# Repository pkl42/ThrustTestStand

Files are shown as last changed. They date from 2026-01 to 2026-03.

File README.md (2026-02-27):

# Motor Thrust Test Stand (ESP32)

An ESP32-based brushless motor thrust test stand for measuring, logging, and analyzing propulsion data of brushless motors and propellers via a web-based interface.

The system controls a brushless ESC, reads multiple sensors in real time, performs automated thrust test sequences using configurable test protocols, and exports results as CSV files for further analysis.

This project was inspired by:  
<https://github.com/avenhaus/thrust_stand/tree/main>  
<https://github.com/iforce2d/thrustTester>  
<https://www.tytorobotics.com/pages/series-1580-1585>

---

## Features

- Brushless motor ESC control (manual and automated)
- Real-time measurement of:
  - Thrust
  - Torque
  - Current
  - Voltage
  - Electrical power
  - RPM
  - Temperature
- Aggregated values including power and thrust-to-power ratio
- **JSON-based test protocols**
  - Multiple protocol definitions supported
  - Up to **10 test protocols stored persistently** on the device
  - Protocols can be uploaded, selected, and executed via the Web UI
- Automated thrust tests based on customizable test protocols
- Live web-based user interface (ESP32 Access Point)
- CSV export of test data
- Sensor calibration via web interface
- Persistent configuration using NVS
- LittleFS-based filesystem

### Safety Features

- Hardware Emergency Stop (E-Stop)
- Propeller cage door safety switch
- **Configurable safety trip concept**
  - Monitors critical parameters such as current, voltage, temperature, RPM, and thrust
  - Automatic motor shutdown when limits are exceeded
  - Safety trips are active during both manual and automated operation
- Visual system state indication via RGB status LED

---

## System Overview

The Thrust Test Stand software is divided into three main components.

### ThrustStand

Hardware abstraction and data acquisition layer:

- Initializes and updates all sensors
- Controls the ESC and throttle
- Accumulates and averages sensor data
- Provides a machine-level state snapshot without UI logic

### ThrustTestController

Automated test execution layer:

- Step-based throttle sequencing
- Acceleration, hold, and deceleration timing
- Test progress tracking
- Execution of stored test protocols
- Test metadata handling (motor, ESC, propeller)
- CSV export to LittleFS

### WebServerController

Web-based control and visualization layer:

- ESP32 operates as a Wi-Fi Access Point
- REST-style API endpoints
- Live JSON status updates
- Sensor calibration endpoints
- Test protocol management (upload, select, delete)
- Test control (start/stop)
- CSV download
- Static HTML/JavaScript frontend served from LittleFS

---

## Documentation

Additional documentation has been split into dedicated files:

- **Hardware design, wiring, and sensors:**  
  [README_Hardware.md](README_Hardware.md)

- **Test protocol format and execution model:**  
  [README_TestProtocol.md](README_TestProtocol.md)

---

## Media

- Overall test stand  
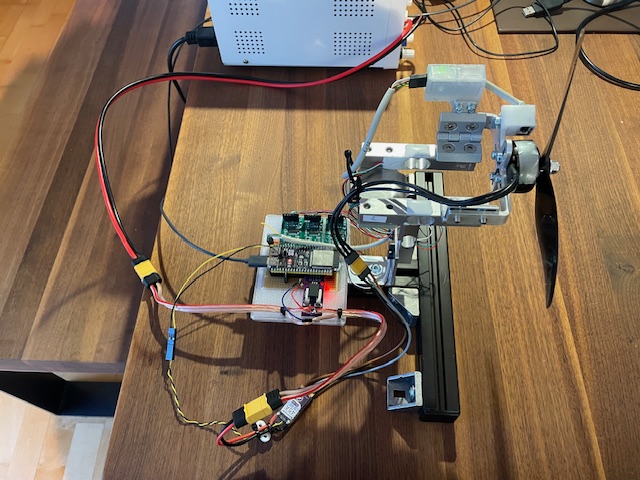
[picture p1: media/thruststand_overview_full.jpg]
Test Stand Overview
  

- ESP32 and sensor electronics overview  
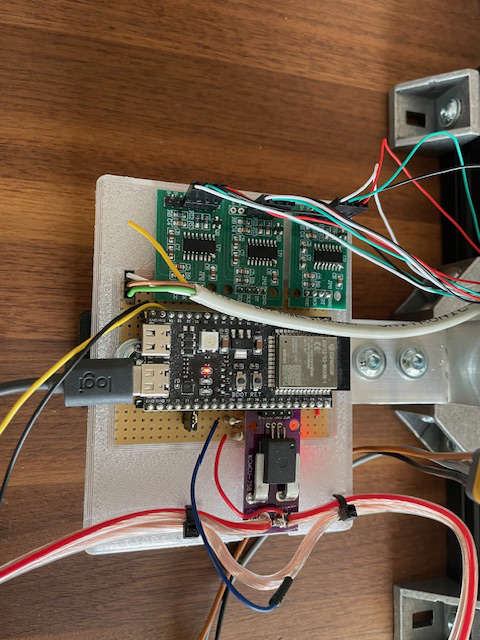
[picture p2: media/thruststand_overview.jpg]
ESP32 Electronic Overview
  

- Web UI Frontend with Live and Test-Section  
Additional Sections are System State, Safety, Configuration, Protocols  
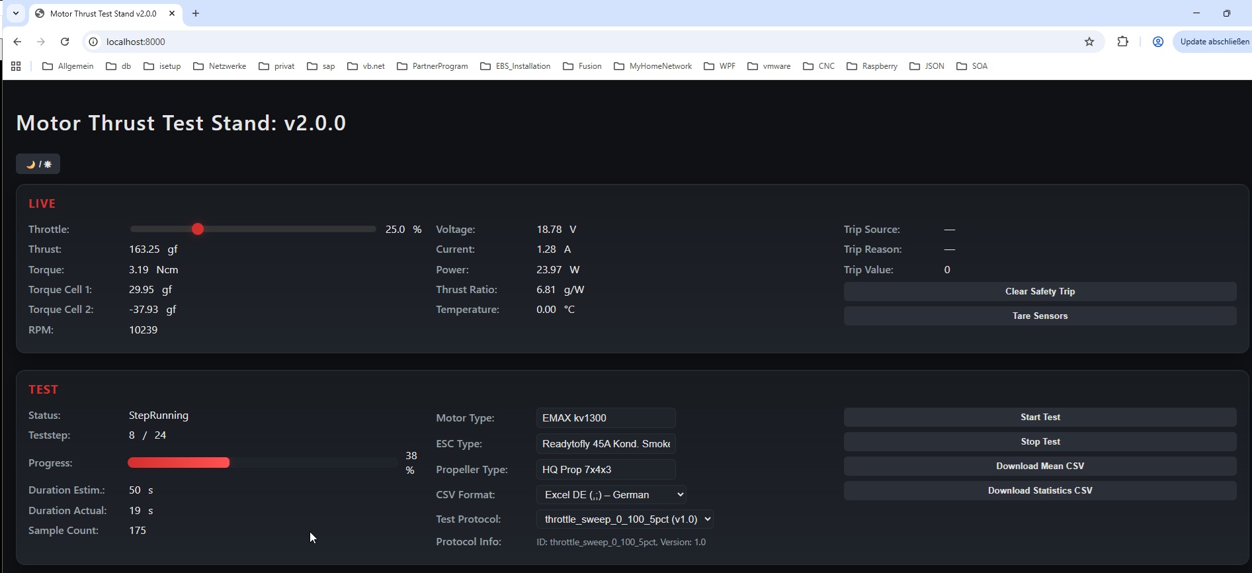
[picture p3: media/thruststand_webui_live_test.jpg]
WEB Front End


---

## Test Data

Each automated test step records:

- Throttle percentage
- Thrust (gf)
- Torque (Ncm)
- Voltage (V)
- Current (A)
- Electrical power (W)
- Efficiency (gf/W)
- RPM
- Temperature (°C)

Data is buffered in memory during the test and written to LittleFS as a CSV file upon completion.

---

## Build Environment

- PlatformIO
- ESP32 Arduino Framework
- Libraries:
  - ESPAsyncWebServer
  - AsyncTCP
  - HX711_ADC
  - Adafruit ADS1X15
  - Adafruit MAX31855
  - Adafruit MLX90614
  - INA226
  - LittleFS

---

## Recent Changes

See [CHANGELOG.md](CHANGELOG.md) for a full list of improvements and fixes.  

---

## Safety Notice

This system controls high-power rotating machinery.

- Always ensure the Emergency Stop is accessible
- Secure the motor and propeller firmly
- Never stand in the propeller plane
- Perform initial tests at low throttle settings

---

## License

Licensed under the Apache License, Version 2.0.

<http://www.apache.org/licenses/LICENSE-2.0>

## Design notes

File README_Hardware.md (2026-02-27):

## Hardware

### Media

Some Images of how the hardware is build up.

- ESP32 Adapter and sensor electronics Top View  
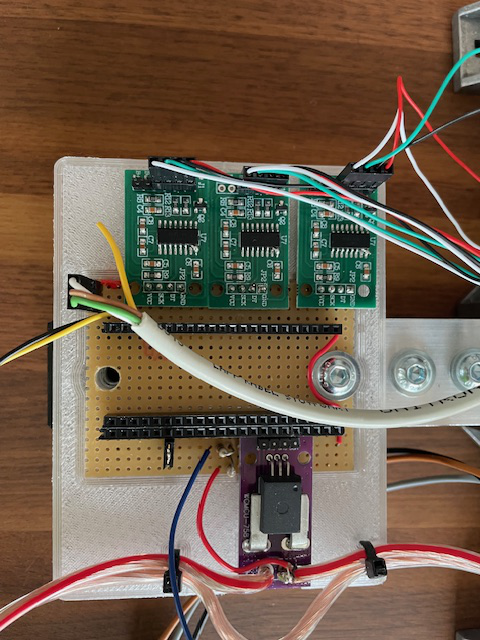
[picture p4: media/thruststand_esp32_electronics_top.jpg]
ESP32 and Sensor Electronics
  
  
- ESP32 Adapter and sensor electronics Bottom View  
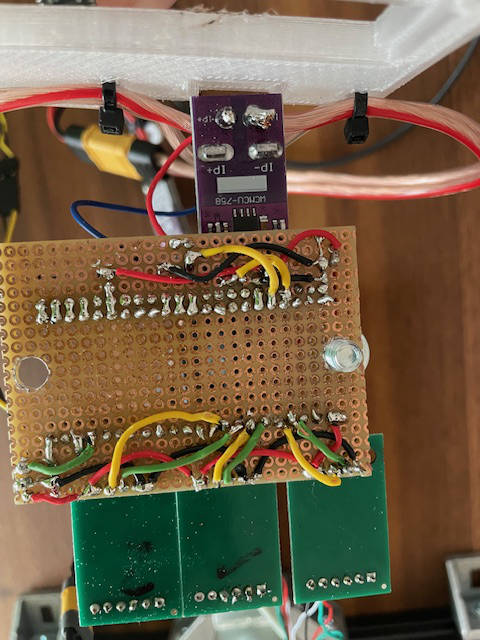
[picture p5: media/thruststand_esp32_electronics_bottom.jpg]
ESP32 and Sensor Electronics
  
  
- Infrared RPM sensor detail  
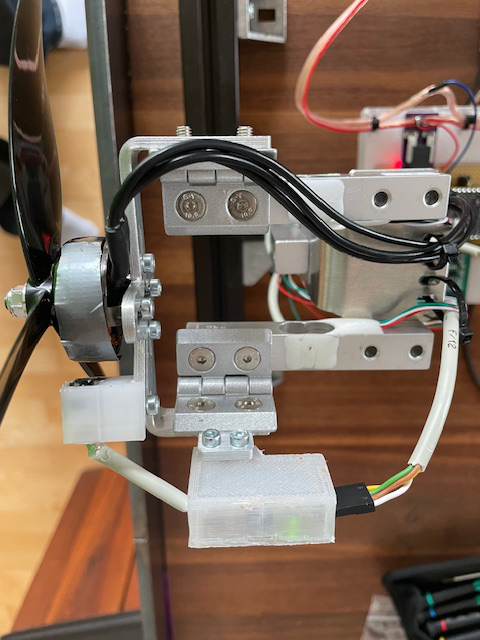
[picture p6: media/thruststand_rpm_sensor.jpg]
Infrared RPM Sensor
  

### Microcontroller

- ESP32-S3 WROOM-1 DevKit

### Sensors

- Thrust:
  - Load cell (5 kg) with HX711 ADC
- Torque:
  - Dual load cells (2 x 2 kg) with HX711 ADC
  - Lever-arm based torque calculation
- Current:
  - ACS758 hall-effect current sensor 50 A
- Voltage:
  - Resistor divider (10 kOhm / 1 kOhm, max approx. 33 V) - see notes below for variants
- RPM:
  - Infrared reflective optical sensor (HW-870 Infrared sensor)
- Temperature:
  - Thermocouple sensor (MAX31855) - prepared but not yet used  
  - Infrared temperature sensor (MAX90614 - HW-691)

### Actuators and Safety

- Brushless ESC (PWM control)
- Configurable pulse range:
  - Default: 1000–2000 µs
  - Allowed: 800–2200 µs
- Hardware Emergency Stop (E-Stop)
- Propeller cage door safety switch
- RGB status LED

---

## Wiring / Pin Assignment

### ESP32-S3 WROOM-1 Pin Mapping

**Note:** All sensors are connected on 3.3V to ESP32 board.

| GPIO | Signal / Name | Direction | Connected Hardware | Notes |
|-----:|---|---|---|---|
| 0* | BOOT | Input | Boot button | Strapping pin |
| 1 | CURRENT_SENSOR_PIN | Input (ADC) | ACS758 current sensor OU2| Current measurement |
| 2 | VOLTAGE_SENSOR_PIN | Input (ADC) | Voltage divider (10k / 1k) | Max ~33 V |
| 4 | HX711_DOUT_1_PIN | Input | HX711 #1 (Thrust, 5 kg) | Data DT|
| 5 | HX711_SCK_1_PIN | Output | HX711 #1 (Thrust, 5 kg) | Clock SCK|
| 6 | HX711_DOUT_2_PIN | Input | HX711 #2 (Torque cell 1, 2 kg) | Data DT|
| 7 | HX711_SCK_2_PIN | Output | HX711 #2 (Torque cell 1, 2 kg) | Clock SCK|
| 13 | RPM_SENSOR_PIN | Input | IR reflective RPM sensor | Digital pulse input DOUT |
| 14 | MOTOR_ESC_PIN | Output (PWM) | Brushless ESC | Throttle control |
| 15 | HX711_DOUT_3_PIN | Input | HX711 #3 (Torque cell 2, 2 kg) | Data DT|
| 16 | HX711_SCK_3_PIN | Output | HX711 #3 (Torque cell 2, 2 kg) | Clock SCK|
| 17 | MAX31855_CS_PIN | Output | MAX31855 thermocouple | SPI chip select |
| 38 / 48 | RGB_BUILTIN_LED | Output | Onboard RGB LED | Status indication |
| 41 | I2C_SCL | I/O | I2C bus | Optional |
| 42 | CAGE_SWITCH_PIN | Input | Cage Door Open/Close Switch | Active safety input |
| 43 | UART_TX0 | Output | USB / Serial | Debug |
| 44 | UART_RX0 | Input | USB / Serial | Debug |
| 47 | ESTOP_PIN | Input | Emergency Stop | Active safety input |

- Strapping pins: GPIO 0, 3, 45, 46. Avoid changing their state during boot.

### Wiring Load Cells to HX711 board

|Wire Color | HX711 board |
|---|---|
| red | E+ |
| black | E- |
| green | A- |
| white | A+ |
| n.c. | B- |
| n.c. | B+ |

### Wiring Infrared Sensor

| Signal/Name |Wire Color  | TCRT5000 IR Infrared board |
|---|---|---|
| 3.3V |white  | Vcc |
| Ground |brown  | GND |
| D0 |green  | D0ut |
| A0 |yellow (n.c.)  | A0 |

### Wiring Current Sensor ASC758

| Signal/Name | Current Sensor ASC758 board |
|---|---|
| 3.3V | Vcc |
| Ground  | GND |
| n.c.  | OU1 |
| CURRENT_SENSOR_PIN,corresponding Voltage | OU2 |

### Wiring ESC

| Signal/Name |Wire Color  |ESC |
|---|---|---|
| GND | black |GND |
| MOTOR_ESC_PIN (PWM) | orange or whie | Signal |

---

Very helpful additions can be found at:
<https://github.com/iforce2d/thrustTester/tree/master>

### Motor speed controller

The ESC should use standard PWM. The default calibration range is 1000 µs for zero throttle and 2000 µs for full throttle.  
The software allows modifying this range from 800 µs to 2200 µs.

To find the correct settings for your ESC, unmount the propeller and move the throttle in the WEB UI to 100%.  
You should reach the maximum motor speed (kv-value × voltage) at 100%.  
If not, increase or decrease the *Max Pulse (µs)* value in the Calibration section of the WEB UI.

### Load cell amplifier

The HX711 can operate at either 10 Hz or 80 Hz update rate. Obviously, the faster rate is preferred, but most HX711 module boards are configured for 10 Hz by default.

To change the update rate to 80 Hz, disconnect the RATE pin (pin 15) from the PCB pad it is soldered to and connect it to VCC.  
The easiest way is to solder it to pin 16, which is located directly next to it.

**Important:** Make sure pin 15 is completely disconnected from the PCB pad. Otherwise, you risk a short circuit when connecting it to VCC.

Please see further details at:
<https://github.com/iforce2d/thrustTester/tree/master>

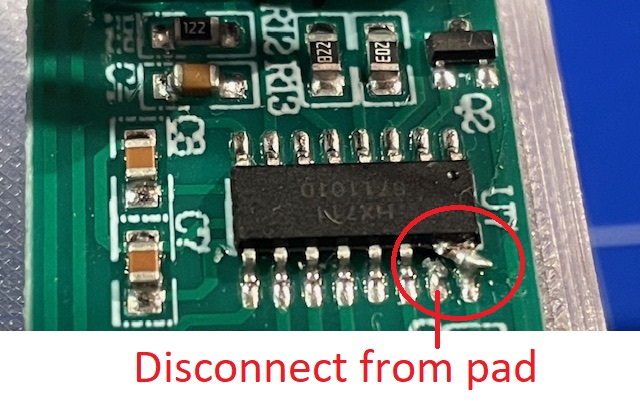
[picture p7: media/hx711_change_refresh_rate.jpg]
HX711 Refresh Rate


The load cells have an arrow indicating the direction of the applied force.  
This arrow should point in the direction where the force is acting, although the load cell will work in both directions.

#### Calibration procedure

1. In the Calibration section, set the *Thrust Cal-Factor* to **1**.
2. In the Live section, press the **“Tare Sensors”** button.
3. Place a defined weight at the center point of the propeller mount.
4. The calibration factor is calculated as:

   **Cal-Factor = Thrust value (Live view) / defined weight**

For calibration, a deflection holder was built to apply the defined weight:

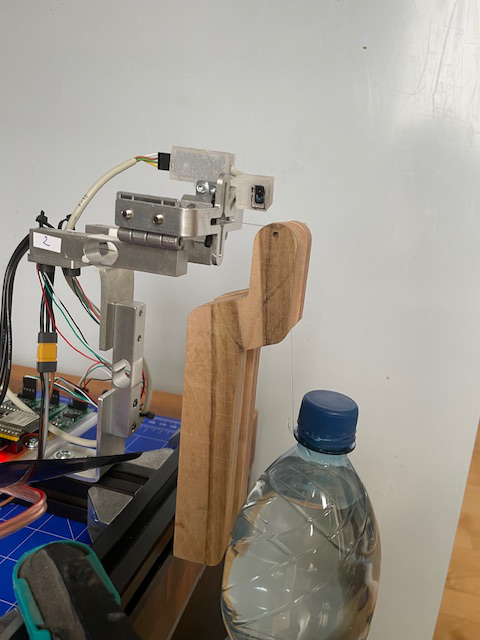
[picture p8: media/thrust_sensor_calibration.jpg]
deflection holder


The water bottle is suspended using a nylon cord and fixed at the center point with a screw or pin, as shown in the picture of the RPM sensor.

Another method is to rotate the thrust stand so the defined weight can be hung directly from the center point.

During calibration, the measured thrust value may drift (slowly decreasing) the longer the weight is applied.  
This behavior is typical for low-cost load cells. To reduce this effect, load cells with an accuracy class such as **C3** or **C4** should be used.

#### Torque sensor calibration

For calibrating the torque sensor, unmount the motor plate (or loosen the hinge screws) so that both load cells do not influence each other.  
This is also the reason why hinges are used for each torque load cell.

To simplify calibration, the torque sensor reports the **absolute torque value**, without information about the direction of rotation.

### Units & Calibration Philosophy

Although thrust is physically a force and its SI unit is **Newton (N)**, this project intentionally uses **grams (g)** as its primary internal unit.  
More precisely, all load-cell-based measurements are expressed in **gram-force (gf)**.

This choice is based on the calibration chain:

- Load cells measure force
- Calibration is performed using a known weight
- The reference weight is determined using a scale that displays grams
- The calibration therefore maps HX711 raw values directly to gram-force

As a result, the internal unit `g` represents **gram-force (gf)**, i.e. the force exerted by a mass of 1 g under Earth gravity.

This approach:

- Matches motor and propeller datasheets, which commonly specify thrust in grams
- Keeps calibration simple and intuitive
- Avoids embedding the gravitational constant into the calibration factor
- Ensures consistency across all load-cell-based measurements

**Torque measurement:**  
Motor torque is measured using two load cells and a known lever arm distance. Internally, torque is represented in **g·m (gram-force meters)**, which is fully consistent with the thrust unit.

For applications requiring SI units, conversion is straightforward:

- 1 g (gf) ≈ 0.00980665 N  
- 1 g·m ≈ 0.00980665 Nm

### Voltage Sensor

The voltage sensor uses a resistor divider of 10 kΩ / 1 kΩ.  
This limits the maximum measurable battery voltage to **36.3 V**, as the ESP32 ADC input must not exceed 3.3 V.  
Keep in mind that on a hard motor stop the voltage will spike. For 6S Batteries (25.2 nominal) this should work.  

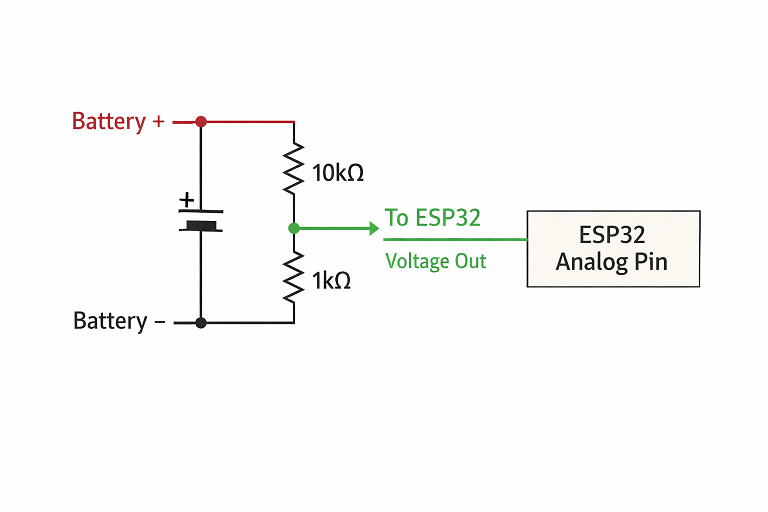
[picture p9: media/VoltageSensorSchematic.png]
Voltage Divider


For more security replace the 1 kΩ by a 820 Ω.  

Since the battery negative terminal must be connected to the ESP32 GND, a pin was directly inserted into the cable.

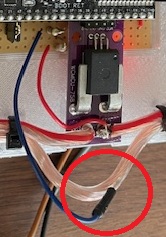
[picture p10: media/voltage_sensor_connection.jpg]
Voltage Minus Connection


For calibration, a laboratory power supply was used and set to a known voltage (e.g. 22 V).  
Adjust the *Voltage Calibration* value in the Calibration section until the displayed live voltage matches the PSU value.

Because the ADC is highly linear, the calibration factor is limited to a range between **0.9 and 1.1**.

### Current Sensor ACS758

The 50 A version of the ACS758 sensor was used, together with a 2.5 mm² cable for the battery current path.  
Even ESCs rated at 45 A (e.g. Flycolor 45A) typically use AWG16 (1.31 mm²), so this setup is sufficiently robust.

In tests with currents up to 33 A, the cable did not heat up.  
XT60 connectors are used between the battery/PSU, current sensor, and ESC.

Calibration options:

1. Manually set the **Current Sensitivity** value (volts per amp), or  
2. Run the motor using a PSU at a known current (e.g. 8 A shown on the PSU) and enter this value into **“Actual Current (A)”**, then press **Set**.

### RPM Sensor TCRT5000 IR Infrared

The IR sensor core was desoldered and repositioned close to the motor rotor.  
Although the sensor sensitivity can be adjusted using a potentiometer, it is difficult to obtain a clean signal due to rotor reflections.

A strip of duct tape was used as a reflective marker, while the rest of the rotor was colored black using a non-permanent whiteboard marker.  
The tape covers approximately half the rotor circumference.

This setup works as long as ambient sunlight is not too strong. A laser-based sensor may be a better alternative.

Tests using propeller reflections were also performed, but at higher RPM the reflection time was too short for reliable detection.

---

## 3D Print Parts Notes

- ESP32 mounting plate: `cad/ESP32SensorAdapter.step`
- Infrared sensor housing: `cad/InfraredSensorHousing.step`
- Electronics housing:
  - `cad/ElectronicHousing.step`
  - `cad/ElectronicHousingCover.step`

M3 heat-set inserts are used for mounting.

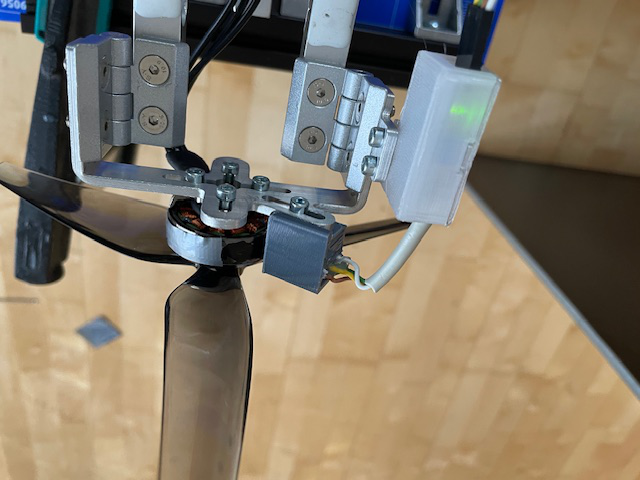
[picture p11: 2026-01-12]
media/rpm_sensor_mount_2.jpg

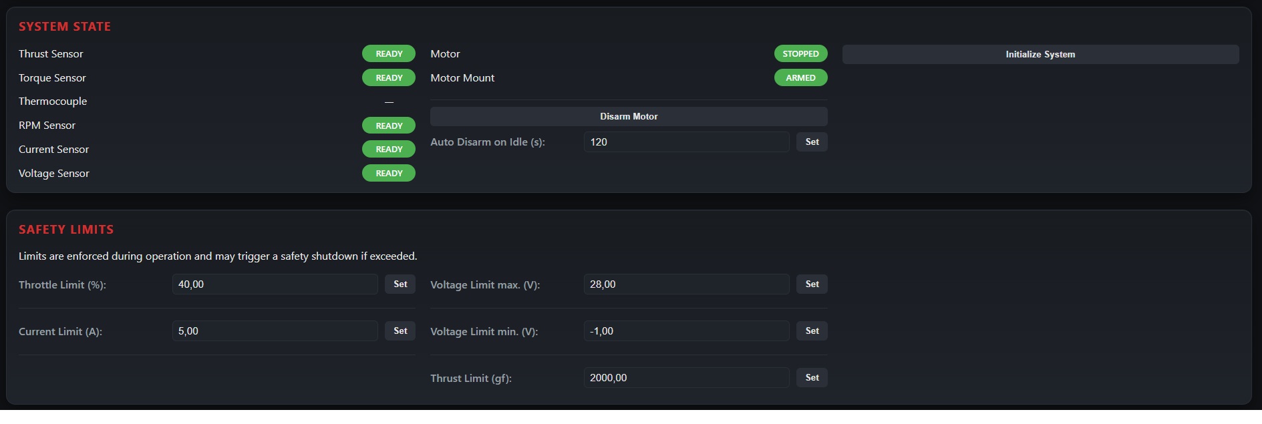
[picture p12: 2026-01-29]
media/thruststand_webui_system_safety.jpg

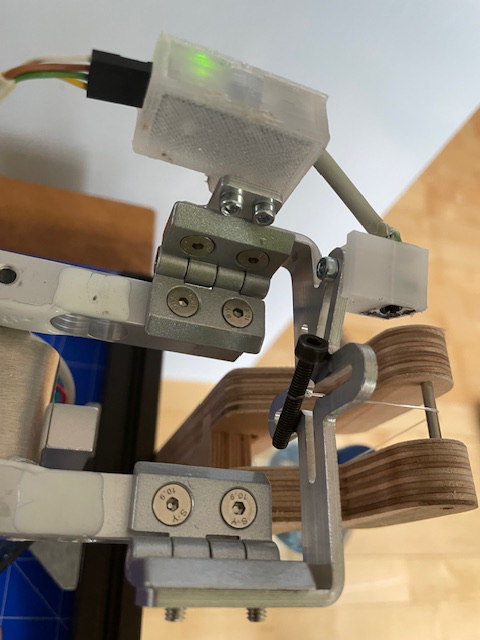
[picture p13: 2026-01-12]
media/rpm_sensor_mount_1.jpg

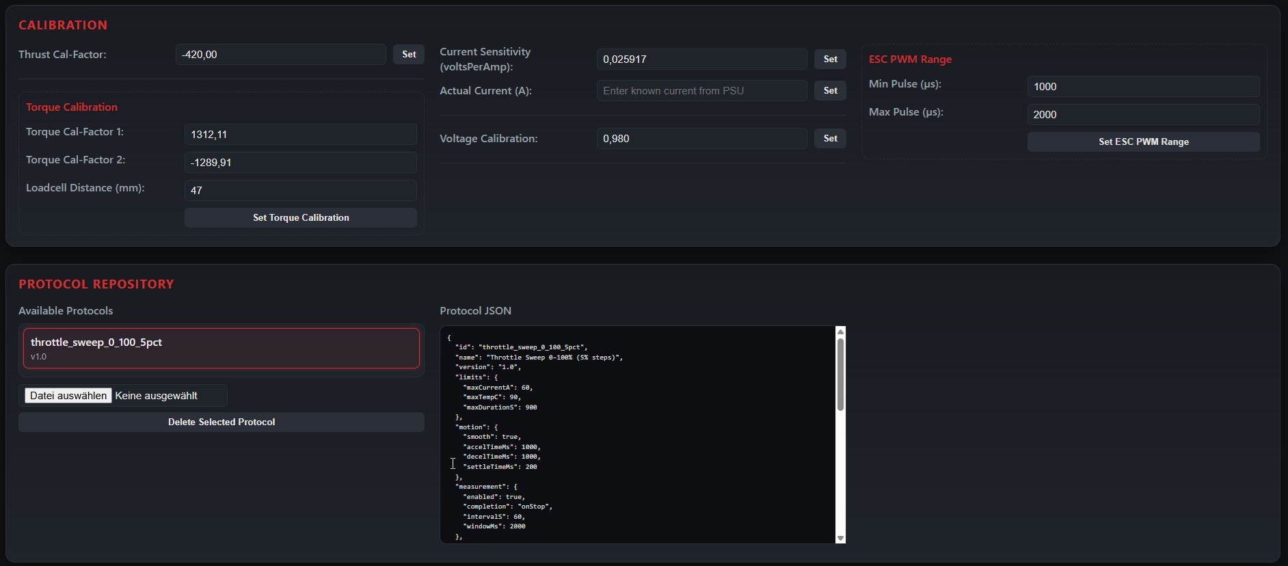
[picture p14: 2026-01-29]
media/thruststand_webui_calib_protocols.jpg

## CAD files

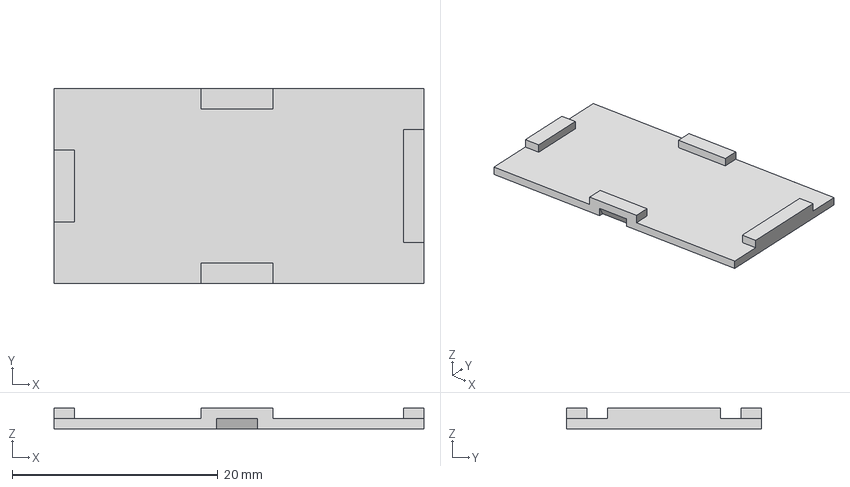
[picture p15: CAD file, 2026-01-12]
cad/ElectronicHousingCover.step
36.0 x 19.0 x 2.00 mm

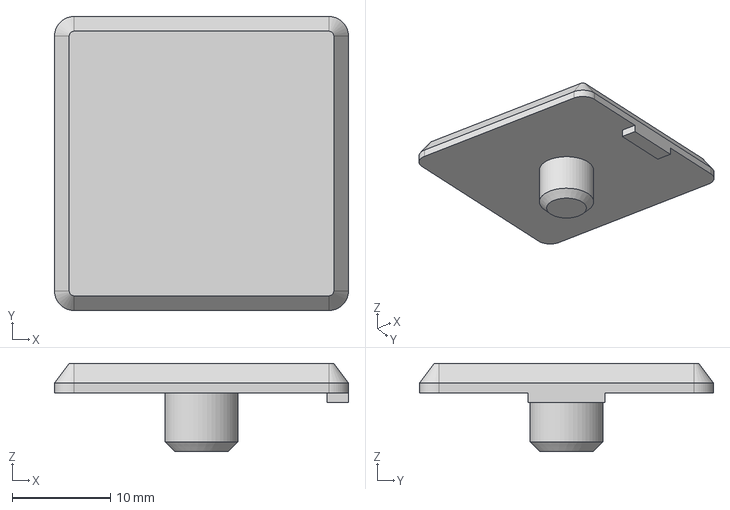
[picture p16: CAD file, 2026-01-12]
cad/Abdeckkappe_20x20 v4.step
30.0 x 30.0 x 9.00 mm

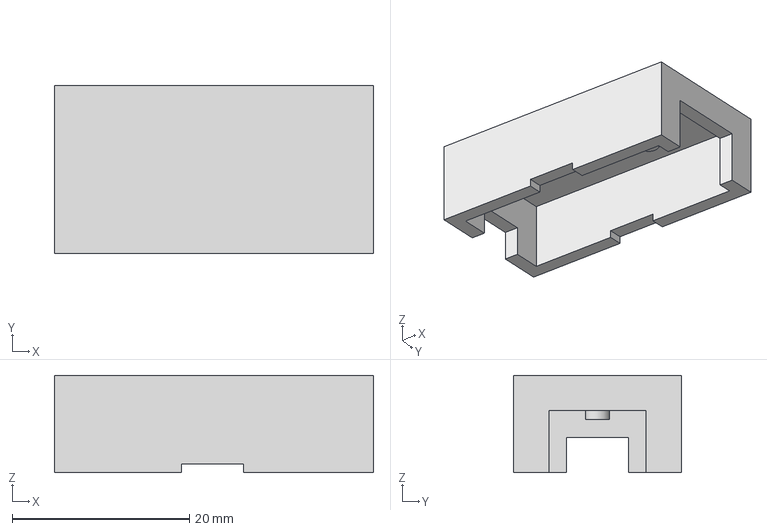
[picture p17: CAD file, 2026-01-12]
cad/ElectronicHousing.step
36.0 x 19.0 x 11.0 mm

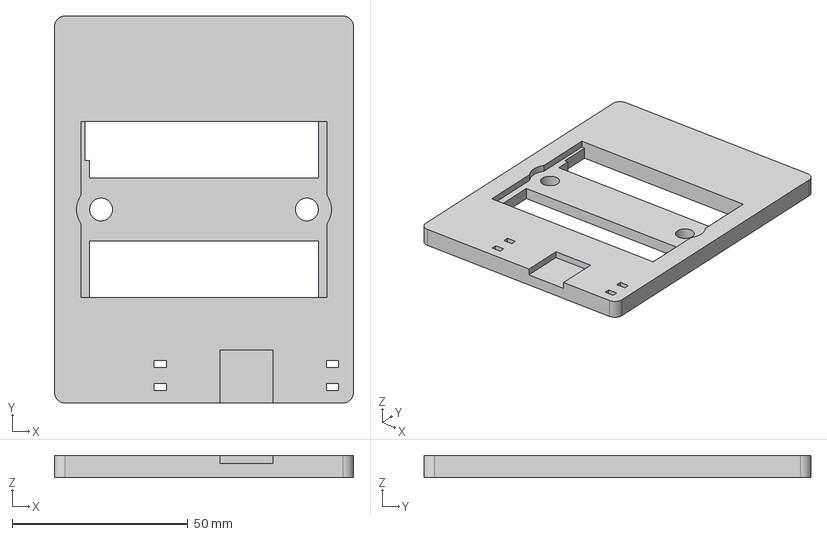
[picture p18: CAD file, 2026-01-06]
cad/ESP32SensorAdapter.step
85.0 x 110.0 x 6.30 mm

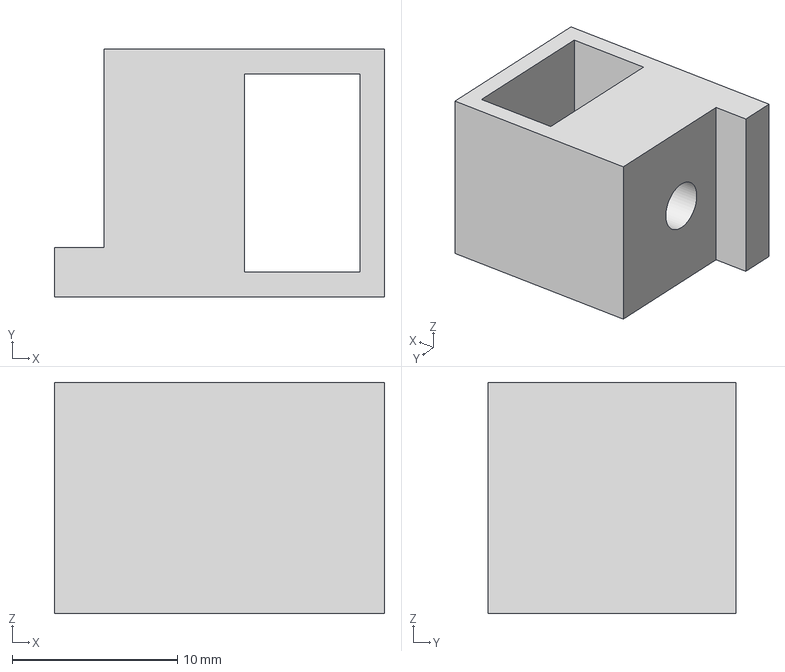
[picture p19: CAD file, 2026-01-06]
cad/InfraredSensorHousing.step
20.0 x 15.0 x 14.0 mm

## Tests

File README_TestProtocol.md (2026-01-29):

# Motor Thrust Test Stand – Test Protocols

This document explains how to define and use **test protocols** for the Motor Thrust Test Stand. Protocols are JSON documents that describe the sequence of steps, motion parameters, measurement configuration, and safety limits.

The goal of the protocol format is to be **safe by default**, **easy to read**, and **flexible where allowed**.

---

## 1. Protocol JSON Structure

A test protocol JSON has the following main sections:

```text
{
  "id": "<unique protocol ID>",
  "name": "<human-readable name>",
  "version": "<protocol version>",
  "estDurationS": 0,
  "unitsTotal": 0,
  "limits": { ... },
  "motion": { ... },
  "measurement": { ... },
  "steps": [ ... ]
}
```

---

## 2. Required vs Optional Fields

### 2.1 Required Fields

| Field | Type | Description |
|---|---|---|
| `id` | string | Unique identifier for the protocol |
| `name` | string | Human-readable name |
| `version` | string | Version of the protocol (e.g. `"1.0"`) |
| `steps` | array | Array of protocol steps |

---

### 2.2 Optional Fields and Default Resolution

All other sections (`limits`, `motion`, `measurement`) are **optional**.

They follow a strict **three-level resolution order**:

1. **Firmware defaults** (defined in the thrust stand firmware)
2. **Protocol header values** (top-level JSON fields)
3. **Step-level overrides** (inside individual steps)

If a field is omitted, the value from the previous level is used.

> **Important:**  
>
> - Firmware defaults always exist and are never undefined  
> - Step-level values only override the fields they explicitly define  

---

## 3. Safety Limits and Non‑Weakening Rules

Safety limits are treated differently from other optional fields.

### 3.1 Sources of Safety Limits

Safety limits can originate from three places:

1. **Firmware hard limits**  
   Absolute safety bounds compiled into the thrust stand firmware, which represents the hardware/sensor limits.

2. **Web UI safety configuration**  
   User-configured safety limits set before starting a test.

3. **Protocol limits**  
   Limits defined in the protocol JSON.

---

### 3.2 Non‑Weakening Principle (Critical)

Safety limits **can only become more restrictive**, never weaker.

This applies at every level:

- Protocol limits **cannot exceed firmware hard limits**
- Protocol limits **cannot exceed Web UI safety settings**
- Step-level limits **cannot exceed protocol limits**

If a protocol requests a weaker limit, the **more restrictive value wins silently**.

---

### 3.3 Limits Section

Defines maximum safe operating parameters:

```json
"limits": {
  "maxCurrentA": 30.0,
  "maxTempC": 80.0,
  "maxDurationS": 900,
  "maxVoltageV": 24.0,
  "minVoltageV": 18.0,
  "maxThrustGF": 5000.0
}
```

| Field | Description | Firmware Setting |
|---|---|---|
| `maxCurrentA` | Maximum allowed motor current (A) | 48 A, see Config.h CURRENT_SENSOR_MAX |
| `maxTempC` | Maximum allowed temperature (°C) | 120 C, see Config.h TEMPERATURE_SENSOR_MAX |
| `maxDurationS` | Maximum allowed test duration (seconds) | 2592000, representing 1 month |
| `maxVoltageV` | Maximum allowed supply voltage | 35 V, see Config.h VOLTAGE_SENSOR_MAX |
| `minVoltageV` | Minimum allowed supply voltage |-1 V, softcoded |
| `maxThrustGF` | Maximum allowed thrust (gram-force) | 5000 g, see Config.h THRUST_SENSOR_MAX |

> If any of these are omitted, the resolved value is taken from firmware or Web UI settings.

---

## 4. Motion Defaults and Overrides

### 4.1 Protocol-Level Motion Defaults

Defines default motion parameters for all steps:

```json
"motion": {
  "smooth": true,
  "accelTimeMs": 1000,
  "decelTimeMs": 1000,
  "settleTimeMs": 200
}
```

| Field | Description |
|---|---|
| `smooth` | Enable throttle smoothing |
| `accelTimeMs` | Acceleration time in milliseconds |
| `decelTimeMs` | Deceleration time in milliseconds |
| `settleTimeMs` | Optional delay after motion completes |

---

### 4.2 Step-Level Motion Overrides

Each step may override motion settings:

```json
"motion": {
  "smooth": false,
  "accelTimeMs": 500
}
```

- Only specified fields override protocol defaults  
- Missing fields inherit protocol-level values  

---

## 5. Measurement Defaults and Overrides

### 5.1 Protocol-Level Measurement Defaults

```json
"measurement": {
  "enabled": true,
  "completion": "onStop",
  "intervalS": 60,
  "windowMs": 2000
}
```

| Field | Description |
|---|---|
| `enabled` | Enable data recording |
| `completion` | `onStop`, `fixedDuration`, or `periodic` |
| `intervalS` | Period between samples (seconds) |
| `windowMs` | Measurement window duration (ms) |

---

### 5.2 Step-Level Measurement Overrides

```json
"measure": {
  "enabled": true,
  "completion": "fixedDuration",
  "windowMs": 1000
}
```

- Only overridden fields are replaced  
- Missing fields inherit protocol-level values  

---

## 6. Steps Section

Each protocol consists of an ordered array of steps:

```json
"steps": [
  { "type": "set", "throttle": 0, "dwellS": 2 },
  { "type": "ramp", "from": 0, "to": 100, "rate": 5 }
]
```

### 6.1 Supported Step Types

| Type | Required Fields | Description |
|---|---|---|
| `set` | `throttle`, `dwellS` | Set throttle and hold |
| `hold` | `throttle`, `dwellS` | Maintain throttle |
| `ramp` | `from`, `to`, `rate` | Continuous ramp |
| `stepSweep` | `from`, `to`, `step`, `dwellS` | Discrete sweep |

---

## 7. Example Protocol

```json
{
  "id": "throttle_sweep_0_100_5pct",
  "name": "Throttle Sweep 0–100% (5% steps)",
  "version": "1.0",

  "limits": {
    "maxCurrentA": 60,
    "maxTempC": 90
  },

  "motion": {
    "smooth": true,
    "accelTimeMs": 1000,
    "decelTimeMs": 1000
  },

  "measurement": {
    "enabled": true,
    "completion": "onStop",
    "windowMs": 2000
  },

  "steps": [
    {
      "type": "set",
      "throttle": 0,
      "dwellS": 2,
      "measure": { "enabled": false }
    },
    {
      "type": "stepSweep",
      "from": 0,
      "to": 100,
      "step": 5,
      "dwellS": 2,
      "measure": {
        "completion": "fixedDuration",
        "windowMs": 1000
      }
    }
  ]
}
```

---

## 8. Key Takeaways

- Firmware defaults always exist  
- Protocol headers define defaults for all steps  
- Steps override only what they explicitly define  
- Safety limits **never weaken**, only tighten  
- Unsafe values are automatically clamped  

This design keeps protocols expressive while guaranteeing safe operation at all times.

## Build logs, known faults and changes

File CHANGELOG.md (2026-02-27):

# Changelog

All notable changes to the Motor Thrust Test Stand project will be documented in this file.

This project does not currently use formal releases.
Changes are documented chronologically.

---

## [Unreleased]

### Added

-

### Changed

-

### Fixed

-

### Removed

-

---

## [v2.2.0] 2026-02-27

### Added

- DShot ESC driver support (configurable RMT channel), but the whole DShot is not working as of now.
- MLX90614 I2C temperature sensor integration
- Sensor abstraction layer to integrate various sensors with the scope (TemperatureSensor)

### Changed

- Refactored `ThrustStand::switchDriver()` to support dynamic driver configuration
- Updated pin configuration structure
- Resolve pin conflict CAGE_SWITCH_PIN, RPM_SENSOR_PIN when using MLX90614 (I2C) or MAX31855 (SPI)

### Fixed

- index.hmtl, main.js were not in sync with github
- After E-Stop, system can be restarted
- Pullup/Pulldown pin logic on E-Stop corrected (inverted)

---

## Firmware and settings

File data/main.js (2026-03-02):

	function setValue(id, value, digits) {
		const el = document.getElementById(id);
		if (!el || value === undefined) return;
		el.value = (typeof digits === "number") ? value.toFixed(digits) : value;
	}
	
	function refreshFromButton(btn) {
		const fieldset = btn.closest('fieldset');
		const apiPath = fieldset?.dataset.api || btn.dataset.api;

		fetch(apiPath)
			.then(r => {
				if (!r.ok) throw new Error("Refresh failed");
				return r.json();
			})
			.then(data => {
				const scope = fieldset || document;

				scope.querySelectorAll('input').forEach(input => {
					if (data.hasOwnProperty(input.id)) {
						input.value = data[input.id];
					}
				});

				alert("Refreshed from device");
			})
			.catch(err => {
				alert("Error during refresh!");
				console.error(err);
			});
	}
	
	function postInputs(apiPath, inputs) {
		const payload = {};

		for (const input of inputs) {
			const path = input.id.split('.');
			let obj = payload;

			for (let i = 0; i < path.length - 1; i++) {
				if (!obj[path[i]]) obj[path[i]] = {};
				obj = obj[path[i]];
			}

			const value =
				input.type === 'number'
					? Number(input.value)
					: input.value;

			obj[path[path.length - 1]] = value;
		}

		// 🔑 Return the Promise
		return fetch(apiPath, {
			method: 'POST',
			headers: { 'Content-Type': 'application/json' },
			body: JSON.stringify(payload)
		})
		.then(r => {
			if (!r.ok) throw new Error("POST failed: " + r.status);
			// try to parse JSON, fallback to text
			return r.text().then(txt => {
				try { return JSON.parse(txt); } catch { return txt; }
			});
		})
		.catch(err => {
			console.error(err);
			alert("Failed to save settings");
			throw err; // propagate to handleAction .catch
		});
	}

	
	// Holds dirty flags for all sections
	const dirtyFlags = {};


	function updateDirtyUI(section) {
		const buttons = document.querySelectorAll(`button[data-section="${section}"]`);
		const isDirty = dirtyFlags[section];

		buttons.forEach(btn => {
			if (isDirty) {
				btn.classList.add('dirty'); // visual highlight only
			} else {
				btn.classList.remove('dirty');
			}
		});
	}
		
	function handleAction(btn) {
		const action = btn.dataset.action;
		const apiPath = btn.dataset.api;
		const rawParams = btn.dataset.params;

		let inputs = [];

		if (rawParams) {
			if (rawParams.endsWith('.*')) {
				// wildcard support, e.g. "limits.*"
				const prefix = rawParams.slice(0, -1); // "limits."
				inputs = Array.from(
					document.querySelectorAll(`input[id^="${prefix}"], select[id^="${prefix}"]`)
				);

			} else {
				// explicit list: a,b,c
				const ids = rawParams.split(',').map(s => s.trim());
				inputs = ids
					.map(id => document.getElementById(id))
					.filter(Boolean);
			}
		}

		if (action.includes('post') && inputs.length) {
			const section = inputs[0].dataset.section; // assume all inputs in same section
			
			console.log("POST inputs:", inputs.map(i => i.id));

			postInputs(apiPath, inputs)
				.then(() => {
					// only reset dirty flag if POST succeeded
					if (section) {
						dirtyFlags[section] = false;
						updateDirtyUI(section);
						// updateExecutionStatusUI(); // recompute isExecutable() if needed
					}
				})
				.catch(err => {
					console.error("Error posting data", err);
					alert("Failed to save settings. Changes not applied.");
				});
		}

		if (action.includes('refresh')) {
			if (btn.dataset.loader) {
				window[btn.dataset.loader]();
			} else {
				refreshFromButton(btn);
			}
		}
	}



	
	function toggleTheme() {
		const root = document.documentElement;
		const current = root.getAttribute("data-theme") || "dark";
		const next = current === "dark" ? "light" : "dark";
		root.setAttribute("data-theme", next);
		localStorage.setItem("theme", next);
	}

	(function initTheme() {
		const saved = localStorage.getItem("theme") || "dark";
		document.documentElement.setAttribute("data-theme", saved);
	})();
	
	

	function isExecutable() {
		const tripped = document.getElementById('safetyBanner').style.display === 'block';
		const dirty = dirtyFlags['safety']; // or iterate all relevant sections
		return !tripped && !dirty;
	}

	
	
	function postParam(apiPath, paramsObj, successMessage) {
		const params = new URLSearchParams();

		// Add each key-value pair from the object
		for (const [key, value] of Object.entries(paramsObj)) {
			params.append(key, value);
		}

		fetch(apiPath, {
			method: 'POST',
			headers: {
				'Content-Type': 'application/x-www-form-urlencoded'
			},
			body: params.toString()
		})
		.then(r => {
			if (!r.ok) throw new Error("Save failed");
			alert(successMessage);
		})
		.catch(err => {
			alert("Error during save!");
			console.error(err);
		});
	}
	
	
    /* -----------------------------
       CALIBRATION
    ------------------------------*/

	function loadCalibration() {
		fetch('/api/calibration')
			.then(r => {
				if (!r.ok) throw new Error("Calibration Values fetch failed");
				return r.json();
			})
			.then(cfg => {

				/* ---------- Version ---------- */
				if (typeof cfg.version === "string") {
					document.title = "Motor Thrust Test Stand " + cfg.version;

					const h1 = document.getElementById('page-title');
					if (h1) {
						h1.textContent = "Motor Thrust Test Stand: " + cfg.version;
					}
				}

				/* ---------- Thrust ---------- */
				setValue('thrust.cal', cfg.thrust?.cal, 2);

				/* ---------- Torque ---------- */
				setValue('torque.cal1',     cfg.torque?.cal1, 2);
				setValue('torque.cal2',     cfg.torque?.cal2, 2);
				setValue('torque.distance_mm', cfg.torque?.distance_mm);

				/* ---------- Current ---------- */
				setValue('current.sensitivity', cfg.current?.sensitivity, 6);

				/* ---------- Voltage ---------- */
				setValue('voltage.calibration', cfg.voltage?.calibration, 3);

				/* ---------- Motor PWM ---------- */
				setValue('motor.pwm_min_us', cfg.motor?.pwm_min_us);
				setValue('motor.pwm_max_us', cfg.motor?.pwm_max_us);
				
				/* ---------- Motor Auto Disarm ---------- */
				setValue('motor.disarm_timeout_s', cfg.motor?.disarm_timeout_s);
				
				/* ---------- ESC Driver Type ---------- */
				setValue('motor.esc_driver_type', cfg.motor?.esc_driver_type);
				const label = escDriverToLabel(cfg.motor?.esc_driver_type);

				setValue('test.esc_driver', label);
			})
			.catch(err => {
				console.error("loadCalibration failed:", err);
				alert("Failed to load calibration values");
			});
	}

	

    /* -----------------------------
       SAFETY LIMIT
    ------------------------------*/
	
	function enforceSafetyTrip() {
		const safetyBanner = document.getElementById('safetyBanner');
		const tripped = safetyBanner.style.display === 'block';

		const slider = document.getElementById('throttle');
		const startTestBtn = document.getElementById('test.start');

		if (tripped) {
			// Reset UI
			slider.value = 0;
			document.getElementById('throttleVal').innerText = "0";

			// Prevent slider interaction
			slider.disabled = true;
			startTestBtn.disabled=true;

		} else {
			// Safety cleared → re-enable slider
			slider.disabled = false;
			startTestBtn.disabled=false;
		}
	}

	
	function loadSafetySettings() {
        fetch('/api/safety')
        .then(r => {
            if (!r.ok) throw new Error("Safety Settings Values fetch failed");
            return r.json();
        })
        .then(data => {
			setValue('limits.throttle_percent', data.limits.throttle_percent, 2);
			setValue('limits.current_a',     data.limits.current_a, 2);
			setValue('limits.voltage_max_v',  data.limits.voltage_max_v, 2);
			setValue('limits.voltage_min_v',  data.limits.voltage_min_v, 2);
			setValue('limits.thrust_gf',     data.limits.thrust_gf, 2);
			setValue('limits.battery_cells', data.limits.battery_cells);
			
			const label = batteryPresetToLabel(data.limits.battery_cells);
			setValue('test.battery_cells', label);
			
			setValue('limits.temperature_c',  data.limits.temperature_c,0);

        })
        .catch(err => {
            console.warn("Failed to load safety settings values:", err);
        });
    }


	// Manual reset Safety button
	function clearSafetyTrip() {
		fetch('/api/safety/clear', { method: 'POST' })
			.then(r => {
				if (!r.ok) throw new Error("Failed to clear safety trip");
				console.log("Safety trip cleared");
			})
			.catch(err => alert(err));
	}
	
	let batteryPresets = {};
	let batteryPresetLabelToId = {};
	
	function batteryPresetToLabel(presetId) {
	return batteryPresets[presetId]?.label ?? 'Custom / Not specified';
	}
	
	function batteryPresetToID(label) {
		return batteryPresetLabelToId[label] ?? null;
	}

	function loadBatteryPresets() {
		fetch('/api/safety/battery-presets')
			.then(r => r.json())
			.then(data => {
				const select = document.getElementById('limits.battery_cells');
				select.innerHTML = '';

				data.presets.forEach(preset => {
					batteryPresets[preset.id] = preset;
					batteryPresetLabelToId[preset.label] = preset.id;

					const opt = document.createElement('option');
					opt.value = preset.id;
					opt.textContent = preset.label;
					select.appendChild(opt);
				});
			});
	}	
	
	function handleBatteryPresetChange(select) {
		const preset = batteryPresets[select.value];
		if (!preset) return;

		// NONE / Calibration preset
		if (preset.cells === 0) {
			if (confirm("Disable battery-based voltage limits?")) {
				setVoltageLimits(preset);
			}
			return;
		}

		if (confirm(
			`Apply default voltage limits for ${preset.label}?\n` +
			`Min: ${preset.voltage_min_v} V\n` +
			`Max: ${preset.voltage_max_v} V`
		)) {
			setVoltageLimits(preset);
		}
	}

	function setVoltageLimits(preset) {
		const minInput = document.getElementById('limits.voltage_min_v');
		const maxInput = document.getElementById('limits.voltage_max_v');

		minInput.value = preset.voltage_min_v;
		maxInput.value = preset.voltage_max_v;

		minInput.dispatchEvent(new Event('input'));
		maxInput.dispatchEvent(new Event('input'));
	}

    /* -----------------------------
       LIVE SECTION
    ------------------------------*/

	function resetThrottleUI(){
		document.getElementById('throttle').value = 0;
		document.getElementById('throttleVal').innerText = "0";
	}
	
	function onThrottleChange(value) {
    if (!isExecutable()) {
        alert("Motor disabled: safety trip active or unarmed or unsaved safety/configuation settings!");
        // reset slider to safe position
        const slider = document.getElementById('throttle');
        slider.value = 0;
        document.getElementById('throttleVal').textContent = '0';
        return;
    }

		document.getElementById('throttleVal').innerText = parseFloat(value).toFixed(1);
		setThrottle(parseFloat(value));
	}
	

	function setThrottle(val) {
		document.getElementById('throttleVal').innerText = val;

		fetch('/api/live/setThrottle', {
			method: 'POST',
			headers: {
				'Content-Type': 'application/x-www-form-urlencoded'
			},
			body: 'throttle=' + encodeURIComponent(val)
		});
	}

	function tare(event) {
		const btn = event.target;
		btn.disabled = true;

		fetch('/api/live/tare', { method: 'POST' })
			.then(response => {
				if (!response.ok) {
					throw new Error('Tare failed');
				}
				return response.text();
			})
			.then(text => {
				console.log('Tare response:', text);
				alert('Sensors tared successfully');
			})
			.catch(err => {
				console.error(err);
				alert('Error taring sensors');
			})
			.finally(() => {
				btn.disabled = false;
			});
	}
   

    function updateLiveStatus() {
        fetch('/api/live/snapshot')
            .then(r => r.json())
            .then(data => {
                document.getElementById('thrust').innerText = data.thrust.toFixed(2);
                document.getElementById('torque').innerText = data.torque.toFixed(2);
				document.getElementById('torqueCell1').innerText = data.torqueCell1.toFixed(2);
				document.getElementById('torqueCell2').innerText = data.torqueCell2.toFixed(2);
                document.getElementById('voltage').innerText = data.voltage.toFixed(2);
                document.getElementById('current').innerText = data.current.toFixed(2);
                document.getElementById('power').innerText = data.power.toFixed(2);
				document.getElementById('thrust_ratio').innerText = data.thrust_ratio.toFixed(2);
                document.getElementById('rpm').innerText = data.rpm.toFixed(0);
                document.getElementById('temperature').innerText = data.temperature.toFixed(2);
                
                document.getElementById('throttleVal').innerText =
                    data.throttle_cmd.toFixed(1);
                document.getElementById('throttle').value =
                    data.throttle_cmd.toFixed(1);

			 // Safety
				const tripped = data.safety_tripped;
				const banner = document.getElementById('safetyBanner');
				if (tripped) {
					banner.style.display = 'block';
					document.getElementById('safetyTripSource').innerText = data.safety_trip_source;
					document.getElementById('safetyTripReason').innerText = data.safety_trip_reason;
					document.getElementById('safetyTripValue').innerText = data.safety_trip_value.toFixed(2);
					
					
				} else {
					banner.style.display = 'none';
					document.getElementById('safetyTripSource').innerText = '—';
					document.getElementById('safetyTripReason').innerText = '—';
					document.getElementById('safetyTripValue').innerText = '0';
				}
				enforceSafetyTrip();
	

            })
            .catch(err => {
                console.warn("Status fetch failed:", err);
            });
    }

    setInterval(updateLiveStatus, 500);

	/* -----------------------------
	   SYSTEM STATE MAPPING
	------------------------------*/

	const SensorStateMap = {
		0: { text: "Uninitialized", css: "state-uninit" },
		1: { text: "Initializing",  css: "state-init" },
		2: { text: "Ready",         css: "state-ready" },
		3: { text: "Error",         css: "state-error" },
		4: { text: "Disabled",      css: "state-disabled" }
	};

	function updateStateElement(id, stateValue) {
		const el = document.getElementById(id);
		if (!el || stateValue === undefined) return;

		const map = SensorStateMap[stateValue] ||
					{ text: "Unknown", css: "state-uninit" };

		el.textContent = map.text;
		el.className = "state " + map.css;
	}
	
	const MotorMountStateMap = {
		0: { text: "Disarmed", css: "state-uninit" },
		1: { text: "Arming",  css: "state-init" },
		2: { text: "Armed",  css: "state-ready" },
		3: { text: "Running", css: "state-ready" }
	};
	
	function updateMotorButton(mountState) {
		const btn = document.getElementById("armMotorBtn");
		if (!btn) return;

		switch (mountState) {
			case 0: // Disarmed
				btn.textContent = "Arm Motor";
				btn.disabled = false;
				break;
			case 2: // Armed
				btn.textContent = "Disarm Motor";
				btn.disabled = false;
				break;
			default: // other states
				btn.textContent = "Arm/Disarm Motor";
				btn.disabled = true;
				break;
		}
	}
	
	function toggleMotor(currentMountState) {
		const btn = document.getElementById("armMotorBtn");
		if (!btn) return;

		const mountState = currentMountState;

		let url = "";
		if (mountState === 0) {
			url = "/api/system/arm";
		} else if (mountState === 2) {
			url = "/api/system/disarm";
		} else {
			console.warn("Motor toggle not allowed in this state:", mountState);
			return;
		}

		btn.disabled = true; // prevent multiple clicks
		fetch(url, { method: "POST" })
			.then(r => {
				if (!r.ok) throw new Error("Request failed: " + r.status);
				return r.json();
			})
			.then(resp => {
				console.log("Motor toggle successful:", resp);
				// Refresh system state after action
				updateSystemState();
			})
			.catch(err => {
				console.error("Motor toggle failed:", err);
				btn.disabled = false; // re-enable on error
			});
	}


	function updateMountStateElement(id, stateValue) {
		const el = document.getElementById(id);
		if (!el || stateValue === undefined) return;

		const map = MotorMountStateMap[stateValue] ||
					{ text: "Unknown", css: "state-uninit" };

		el.textContent = map.text;
		el.className = "state " + map.css;
	}
	
	const ActuatorStateMap = {
		0: { text: "Uninitialized", css: "state-uninit" },
		1: { text: "Initializing",  css: "state-init" },
		2: { text: "Ready",         css: "state-ready" },
		3: { text: "Active",        css: "state-ready" },
		4: { text: "Stopped",       css: "state-ready" },
		5: { text: "Error",         css: "state-error" },
		6: { text: "Disabled",      css: "state-disabled" },
		7: { text: "E-Stop",      css: "state-error" }
	};	
	
	function updateActuatorElement(id, stateValue) {
		const el = document.getElementById(id);
		if (!el || stateValue === undefined) return;

		const map = ActuatorStateMap[stateValue] ||
					{ text: "Unknown", css: "state-uninit" };

		el.textContent = map.text;
		el.className = "state " + map.css;
	}
	
	function updateSystemState() {
		fetch('/api/system')
			.then(r => r.json())
			.then(s => {

				updateStateElement("state-thrust", s.thrust);
				updateStateElement("state-torque", s.torque);
				updateStateElement("state-thermo", s.temperature);
				updateStateElement("state-rpm", s.rpm);
				updateStateElement("state-current", s.current);
				updateStateElement("state-voltage", s.voltage);

				updateActuatorElement("state-motor", s.motor);
				updateMountStateElement("state-motor-mount", s.motor_mount);
				
				latestMotorMount = s.motor_mount;      // store globally
				updateMotorButton(s.motor_mount);

			})
			.catch(err => {
				console.warn("System state fetch failed:", err);
			});
	}
	
	setInterval(updateSystemState, 1000);
	
	
	async function initializeSystem() {
		const response = await fetch("/api/system/initialize", { method: "POST" });
		const result = await response.json();

		alert(result.message);

		// Optionally refresh system state
		updateSystemState();
	}
	
	let escDrivers={};
	let escDriversLableToId={};
	
	
	function escDriverToLabel(id) {
		return escDrivers[id]?.label ?? 'None';
	}
	
	function escDriverToId(label) {
		return escDriversLableToId[label];
	}
	
	// Populate ESC driver select
	function loadEscDrivers() {
		fetch('/api/calibration/escProtocols')
			.then(r => r.json())
			.then(data => {
				const sel = document.getElementById('motor.esc_driver_type');
				sel.innerHTML = '';
				data.esc_drivers.forEach(d => {
					escDrivers[d.id] = d;
					escDriversLableToId[d.label]=d.id;
					const opt = document.createElement('option');
					opt.value = d.id;
					opt.text = d.label;
					sel.add(opt);
				});
			});
	}


   	/* -----------------------------
	   TEST SECTION
	------------------------------*/
	const StartError = {
		0: "ok",
		1: "already_running",
		2: "missing_motor_type",
		3: "missing_propeller_type",
		4: "tare_failed",
		5: "invalid_protocol",
		6: "safety_locked",
		7: "MotorNotArmed"
	};

	function startErrorToString(code) {
		return StartError[code] || "unknown_error";
	}
	
	const TestStateMap = {
		0: { text: "Idle", css: "state-uninit" },
		1: { text: "StepInit",  css: "state-init" },
		2: { text: "StepRunning", css: "state-ready" },
		3: { text: "Completed", css: "state-ready" },
		4: { text: "Aborted", css: "state-error" },
		5: { text: "Failed", css: "state-error" }
	};
	



	let  lastTestRunning=null;

	function updateTestStatus() {
		fetch('/api/test')
			.then(r => r.json())
			.then(data => {
				if (data.running !== undefined) {

					const running = !!data.running;

					const map = TestStateMap[data.execState ?? 0] ;

					document.getElementById('test_status').innerText =map.text;

					document.getElementById('test_step').innerText =
						data.unitsDone ?? 0;

					document.getElementById('test_steps_total').innerText =
						data.unitsTotal ?? 0;
						
					document.getElementById('estDurationS').innerText =
						data.estDurationS.toFixed(0) ?? 0;						

					document.getElementById('actDurationS').innerText =
						data.durationS.toFixed(0) ?? 0;						

					const progress = Math.max(
						0,
						Math.min(100, data.progress ?? 0)
					);

					document.getElementById('testProgress').value = progress;
					document.getElementById('testProgressText').innerText =
						progress.toFixed(0) + " %";

					// visually dim when idle
					document.getElementById('testProgress').classList.toggle(
						'test-idle',
						!running
					);

					/* -------- Protocol Repository lock -------- */
					if (lastTestRunning !== running) {
						setRepoEnabled(!running);
						lastTestRunning = running;
					}
					
					document.getElementById('thrust_samples').innerText = data.thrust_samples  ?? 0;

				}
			})
			.catch(err => {
				console.warn("Status fetch failed:", err);
			});
	}

	setInterval(updateTestStatus, 1000);	

	document.addEventListener("DOMContentLoaded", () => {
		loadProtocols();
	});
	
	async function startTest() {
		if (!testProtocolSelection) {
			alert("Please select a test protocol");
			return;
		}
		if (!isExecutable()) {
			alert("Motor disabled: safety trip active or unarmed or unsaved safety/configuation settings!");
			return;
		}
		const escDriverTypeId=escDriverToId(document.getElementById("test.esc_driver").value);
		const batteryTypeId= batteryPresetToID  (document.getElementById("test.battery_cells").value);

		const configPayload = {
			motorType: document.getElementById("test.motor_type").value,
			escType: document.getElementById("test.esc_type").value,
			propellerType: document.getElementById("test.prop_type").value,
			csvFormat: document.getElementById("test.csv_format").value,
			protocolID: testProtocolSelection.id,
			protocolVersion: testProtocolSelection.version,
			batteryCells: batteryTypeId,
			escDriverType: escDriverTypeId
		};

		try {
			/* 1) PUT config */
			const r = await fetch("/api/test/config", {
				method: "PUT",
				headers: { "Content-Type": "application/json" },
				body: JSON.stringify(configPayload)
			});
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

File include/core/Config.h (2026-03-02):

#ifndef PINOUT_H
#define PINOUT_H
#include <IPAddress.h>

#define THRUSTSTAND_APP_NAME "Motor Thrust Test Stand"
#define THRUSTSTAND_APP_VERSION "v2.2.1"
#define THRUSTSTAND_CSV_VERSION "1.2"

// #define THRUSTSTAND_GIT_HASH        "a9c4e2f"
#define THRUSTSTAND_BUILD_DATE __DATE__ " " __TIME__

/*
ESP32 S3 Pins
https://www.wemos.cc/en/latest/s3/s3.html
---+------+----+-----+-----+-----------+---------------------------
No.| GPIO | IO | RTC | ADC | Default   | Function
---+------+----+-----+-----+-----------+---------------------------
   |   0* | IO |   0 |     | Boot      | Button
   |   1  | IO |   1 | 1_0 |           | CURRENT_SENSOR_PIN ACS758
   |   2  | IO |   2 | 1_1 |           | Voltage
   |   3* | IO |   3 | 1_2 |           |
   |   4  | IO |   4 | 1_3 |           | HX711-DOUT1
   |   5  | IO |   5 | 1_4 |           | HX711-CLK1
   |   6  | IO |   6 | 1_5 |           | HX711-DOUT2
   |   7  | IO |   7 | 1_6 |           | HX711-CLK2
   |   8  | IO |   8 | 1_7 |           | RPM_SENSOR_PIN
   |   9  | IO |   9 | 1_8 |           |
   |  10  | IO |  10 | 1_9 | SPI-SS    |
   |  11  | IO |  11 | 2_0 | SPI-MOSI  |
   |  12  | IO |  12 | 2_1 | SPI-SCK   | default Adafruit_MAX31855 SCK
   |  13  | IO |  13 | 2_2 | SPI-MISO  | default Adafruit_MAX31855 MISO
   |  14  | IO |  14 | 2_3 |           | ESC-PWM
   |  15  | IO |  15 | 2_4 |           | HX711-DOUT3
   |  16  | IO |  16 | 2_5 |           | HX711-CLK3
   |  17  | IO |  17 | 2_6 |           | MAX31855_CS_PIN
   |  18  | IO |  18 | 2_7 |           |
   |  19  | IO |  19 | 2_8 | USB/JTAG  |
   |  20  | IO |  20 | 2_9 | USB/JTAG  |
   |  21  | IO |  21 |     |           |
   |  38  | IO |     |     |           | RGB_BUILTIN_LED
   |  39  | IO |     |     |           |
   |  40  | IO |     |     |           |
   |  41  | IO |     |     | I2C_SCL   | MLX90614 SCL
   |  42  | IO |     |     | I2C_SDA   | MLX90614 SDA
   |  43  | IO |     |     | UART_TX0  |
   |  44  | IO |     |     | UART_RX0  |
   |  45* | IO |     |     |           |
   |  46* | IO |     |     |           |
   |  47  | IO |     |     |           | ESTOP_PIN
   |  48  | IO |     |     |           | CAGE_SWITCH_PIN
---+------+----+-----+-----+-----------+---------------------------
* Strapping pins: IO0, IO3, IO45, IO46
*/

// if this clause does not work, but the builtin RGB is working
// just add this into platformio.ini
//
// build_flags =
//     -DHAS_RGB_LED
//     -DRGB_BUILTIN=48
// There is currently a bug in the ESP32-S3 neopixelWrite() code. This will produce the
// following errors and the RGB LED will not light up.:
//  E (19) rmt: rmt_set_gpio(526): RMT GPIO ERROR
//  E (19) rmt: rmt_config(686): set gpio for RMT driver failed
//  ==> Remove the #ifdef RGB_BUILTIN logic in the neopixelWrite() code.
// ==> or i choose RGB_BUILTIN_LED

// #if defined(CONFIG_IDF_TARGET_ESP32S3) && !defined(RGB_BUILTIN)
// #define RGB_BUILTIN 48
// #define HAS_RGB_LED 1
// #endif

#define RGB_BUILTIN_LED 38
#define HAS_RGB_LED 1

#define HX711_DOUT_1_PIN 4 // mcu > HX711 no 1 dout pin 5kg
#define HX711_SCK_1_PIN 5  // mcu > HX711 no 1 sck pin 5kg

#define HX711_DOUT_2_PIN 6 // mcu > HX711 no 2 dout pin 2kg-1
#define HX711_SCK_2_PIN 7  // mcu > HX711 no 2 sck pin 2kg-1

#define HX711_DOUT_3_PIN 15 // mcu > HX711 no 3 dout pin 2kg-2
#define HX711_SCK_3_PIN 16  // mcu > HX711 no 3 sck pin 2kg-2

#define MOTOR_ESC_PIN 14

#define RPM_SENSOR_PIN 8 // GPIO pin connected to the optical sensor

#define CURRENT_SENSOR_PIN 1 // GPIO pin for current sensor ACS758

#define VOLTAGE_SENSOR_PIN 2 // GPIO pin for voltage sensor

#define MAX31855_CS_PIN 17

#define ESTOP_PIN 47

#define CAGE_SWITCH_PIN 48

#define MLX90614_SCL_PIN 41 // with pin 41 the standard I2C SCL pin is used
#define MLX90614_SDA_PIN 42 // with pin 42 the standard I2C SDA pin is used

// microsecond delay after writing sck pin high or low. This delay could be required for faster mcu's.
// So far the only mcu reported to need this delay is the ESP32 (issue #35), both the Arduino Due and ESP8266 seems to run fine without it.
// Change the value to '1' to enable the delay.
#define SCK_DELAY 0 // default value: 0

// if you have some other time consuming (>60μs) interrupt routines that trigger while the sck pin is high, this could unintentionally set the HX711 into "power down" mode
// if required you can change the value to '1' to disable interrupts when writing to the sck pin.
#define SCK_DISABLE_INTERRUPTS 0 // default value: 0

// ==============================================
// Installed Sensors
// ==============================================

const bool THRUST_SENSOR_INSTALLED = true;
const bool TORQUE_SENSOR_INSTALLED = true;
const bool CURRENT_SENSOR_INSTALLED = true;
const bool VOLTAGE_SENSOR_INSTALLED = true;

const bool RPM_SENSOR_INSTALLED = true;

// ==============================================
// Temperature Sensor Selection
// ==============================================
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

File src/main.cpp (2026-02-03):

/*
 * SPDX-FileCopyrightText: 2026 Peter Ludwig
 *
 * SPDX-License-Identifier: Apache-2.0
 */

#include <Arduino.h>
#include <esp_log.h>
#include <pgmspace.h>
#include <freertos/semphr.h>
#include "esp_heap_caps.h"
#include "core/Config.h"
#include "core/ThrustStand.h"
#include "protocol/TestProtocolExecutor.h"
#include "protocol/ProtocolManager.h"
#include "recorder/TestDataRecorder.h"
#include "comms/WebServerController.h"
#include "comms/WiFiAPController.h"

#define SERIAL_SPEED 115200

ThrustStand thrustStand;
TestDataRecorder dataRecorder(thrustStand);
ProtocolManager protocolManager;
TestProtocolExecutor testExecutor(thrustStand);

WiFiAPController wifiAP(AP_SSID, AP_PASSWORD);

// Global Instance
WebServerController *webServer;

SemaphoreHandle_t dataMutex;

// Forward Declaration der Tasks
void thrustStandTask(void *parameter);
void webTask(void *parameter);
// void escUpdateTask(void *parameter); // D-Shot is under construction

void printHeapStatus(const char *tag);

void setup()
{
  Serial.begin(SERIAL_SPEED);
  delay(200);
  esp_log_level_set("*", ESP_LOG_INFO);
  ESP_LOGI("setup", "# %s %s | %s ", THRUSTSTAND_APP_NAME, THRUSTSTAND_APP_VERSION, THRUSTSTAND_BUILD_DATE);
  Serial.flush();

  // WiFi AP starten
  wifiAP.setAPConfig(AP_IP, AP_GATEWAY, AP_SUBNET);
  wifiAP.begin();

  // start Thrust Stand
  while (!thrustStand.init())
  {
    ESP_LOGE("setup", "thrust stand initializing failed!");
    delay(1000);
  };

  dataRecorder.begin();
  // initialize Test Executor
  testExecutor.begin();
  testExecutor.setRecorder(&dataRecorder);

  webServer = new WebServerController(&thrustStand, &testExecutor, &dataRecorder, &protocolManager);

  // Mutex für shared data
  dataMutex = xSemaphoreCreateMutex();
  if (!dataMutex)
  {
    ESP_LOGE("setup", "Failed to create Mutex!");
  }

  // Sensor/Motor-Task Core 0
  xTaskCreatePinnedToCore(
      thrustStandTask,
      "thrustStandTask",
      4096,
      NULL,
      2,
      NULL,
      0 // Core 0
  );

  // D-Shot is under construction
  // xTaskCreatePinnedToCore(
  //     escUpdateTask,
  //     "escUpdateTask",
  //     2048,
  //     NULL,
  //     2,
  //     NULL,
  //     0 // Core 0
  // );

  // Webserver-Task Core 1
  xTaskCreatePinnedToCore(
      webTask,
      "WebTask",
      8192,
      NULL,
      1,
      NULL,
      1 // Core 1
  );

  printHeapStatus("setup");
}

void loop()
{
}

// ================= Task Implementierungen =================

// Sensor & Motor Task (Core 0)
void thrustStandTask(void *parameter)
{
  const TickType_t loopDelay = pdMS_TO_TICKS(10); // 100 Hz

  while (true)
  {
    // 1️⃣ Update hardware (motor, sensors, ESC state machine)
    thrustStand.update();

    // 2️⃣ Run thrust test state machine (ONLY here!)
    testExecutor.update();
    dataRecorder.update();

    // 3️⃣ Protect shared data only if actually accessed
    if (dataMutex != nullptr)
    {
      if (xSemaphoreTake(dataMutex, 0) == pdTRUE)
      {
        // Example:
        // sharedData = thrustStand.getCurrentData();

        xSemaphoreGive(dataMutex);
      }
    }

    vTaskDelay(loopDelay);
  }
}

void escUpdateTask(void *parameter)
{
  const TickType_t loopDelay = pdMS_TO_TICKS(1); // 1 kHz

  while (true)
  {
    thrustStand.updateEsc(); // only calls driver->tick()
    vTaskDelay(loopDelay);
  }
}

// Webserver Task (Core 1)
void webTask(void *parameter)
{
  // Webserver starten
  webServer->begin();

  // Task Loop
  while (true)
  {
    // AsyncWebServer erledigt alles andere
    vTaskDelay(pdMS_TO_TICKS(1000));
  }
}

// used for checking free space for increasing the MAX_RECORD_STEPS in TestDataRecorder
void printHeapStatus(const char *tag)
{
  size_t free8 = heap_caps_get_free_size(MALLOC_CAP_8BIT);
  size_t free32 = heap_caps_get_free_size(MALLOC_CAP_32BIT);
  size_t largest = heap_caps_get_largest_free_block(MALLOC_CAP_8BIT);

  ESP_LOGI(tag, "Heap free 8bit : %u bytes", free8);
  ESP_LOGI(tag, "Heap free 32bit: %u bytes", free32);
  ESP_LOGI(tag, "Heap largest  : %u bytes", largest);
}

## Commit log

2026-01-06 modified: README.md new file: media/esp32_electronics.jpg new file: media/esp32_electronics_bottom.jpg new file: media/rpm_sensor_detail.jpg
2026-01-06 modified: README.md deleted: media/esp32_electronics_bottom.jpg new file: media/thruststand_esp32_electronics_bottom.jpg new file: media/thruststand_esp32_electronics_top.jpg renamed: media/esp32_ele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
2026-01-06 modified: README.md new file: cad/ESP32SensorAdapter.step new file: cad/ElectronicHousing.step new file: cad/ElectronicHousingCover.step new file: cad/InfraredSensorHousing.step new file: media/Volta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
    [ESP32SensorAdapter.step, ElectronicHousing.step, ElectronicHousingCover.step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]
2026-01-12 various updated modified: README.md modified: data/index.html modified: include/BusVoltageADCSensor.h renamed: include/pinOut.h -> include/Config.h modified: include/CurrentACS758Sensor.h modified: i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
2026-01-12 Updated step-files new file: cad/Abdeckkappe_20x20 v4.step modified: cad/ElectronicHousing.step modified: cad/ElectronicHousingCover.step
    [Abdeckkappe_20x20 v4.step, ElectronicHousing.step, ElectronicHousingCover.step]
2026-01-16 Safety feature, statistic sample data output added modified: README.md renamed: src/current_ina226_sensor.cpp -> archive/current_ina226_sensor.cpp renamed: include/current_ina226_sensor.h -> archive/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
2026-01-29 version 2.0 new file: ProtocolSemanticsJson.md new file: archive/TestProtocolValidator.cpp new file: archive/TestProtocolValidator.h modified: data/index.html new file: data/main.js new file: data/pr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
2026-01-29 update readme deleted: ProtocolSemanticsJson.md modified: README.md new file: README_Hardware.md new file: README_TestProtocol.md new file: TestProtocol.schema.json new file: media/thruststand_overvi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
2026-02-03 Battery Cells added, bug fixes modified: data/index.html modified: data/style.css modified: include/actuators/MotorESC.h new file: include/actuators/esc/DShotEscDriver.h new file: include/actuators/e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
    [Config.h, DShotEscDriver.cpp, EscSignalDriver.h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]
2026-02-27 various updates, see details on readme for version 2.2.0 modified: README_Hardware.md modified: data/index.html modified: data/main.js modified: include/core/Config.h modified: include/core/ThrustSta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
2026-03-02 max Temperature Safety Limit added on webui
